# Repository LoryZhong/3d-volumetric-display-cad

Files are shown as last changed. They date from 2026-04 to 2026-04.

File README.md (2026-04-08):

# 3D Volumetric Display — Hardware Design Files

Mechanical CAD and PCB design files for a rotational swept-volume volumetric display based on persistence of vision (POV). Structural components were designed in SolidWorks and fabricated by FDM 3D printing (PLA, with PETG for the motor damper). The custom HUB75E adapter PCB was designed in KiCad.

This repository accompanies the software driver at [LoryVox](https://github.com/LoryZhong/LoryVox).

## Assembly Overview

The mechanical structure is divided into three subsystems:

### Rotate Part — Core Rotating Assembly

The central rotating body that carries all on-rotor electronics. Includes the core (with Raspberry Pi 4 mounting bosses and bearing locators), plug, slip-ring cylinder (sized for the ASL9013 2-line slip ring), bottom bearing ring, GT2 pulley bore, half-disc photo-interrupter flag, and top cover.

- Upper bearing: 6015 deep-groove ball bearing (bore large enough for the Raspberry Pi to pass through during assembly)
- Lower bearing: 6804 deep-groove ball bearing (bore sized for the ASL9013 slip ring)
- Bearings are retained by interference-fit bosses — no adhesive required

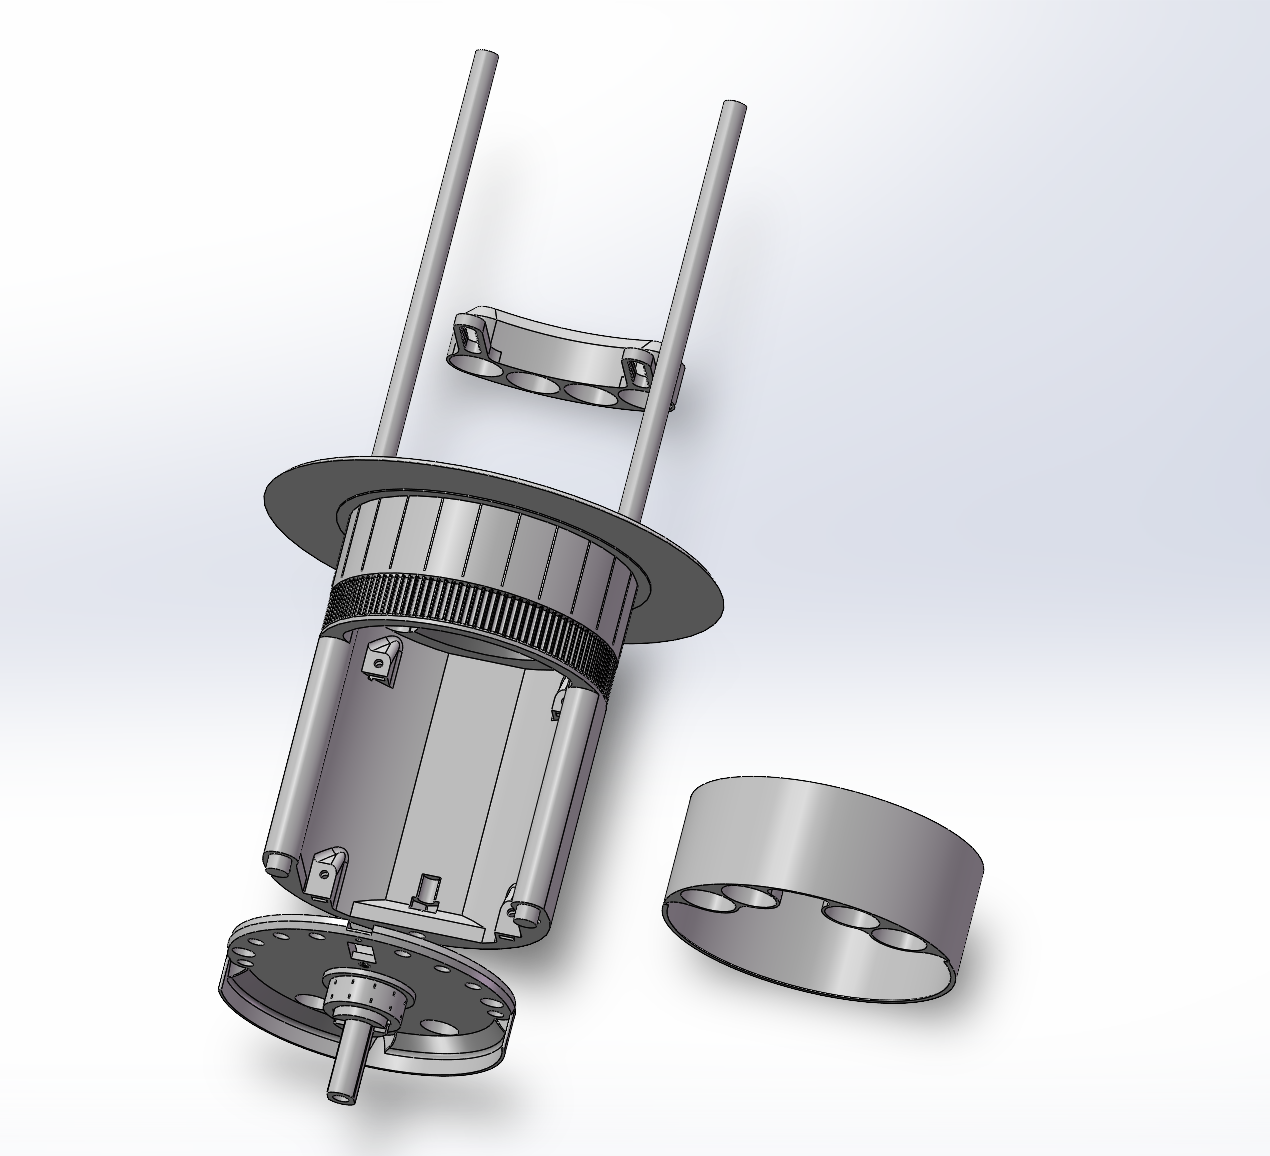
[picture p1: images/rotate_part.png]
Rotate Part


**Contents of `rotate-part/`:** Core, plug, slip-ring cylinder, bottom bearing ring, half-disc flag, top cover.

### Frame — LED Panel Mounting Frame

Rectangular frames that hold each HUB75E LED panel (P2.5 64x64) at the correct radial distance from the rotation axis. Carbon-fibre rods (6 mm dia.) connect the frames to the core assembly. Version 2 redesigned the rod socket diameter to 6.1 mm with clearance chamfers, allowing post-print finishing with a 6.1 mm drill bit.

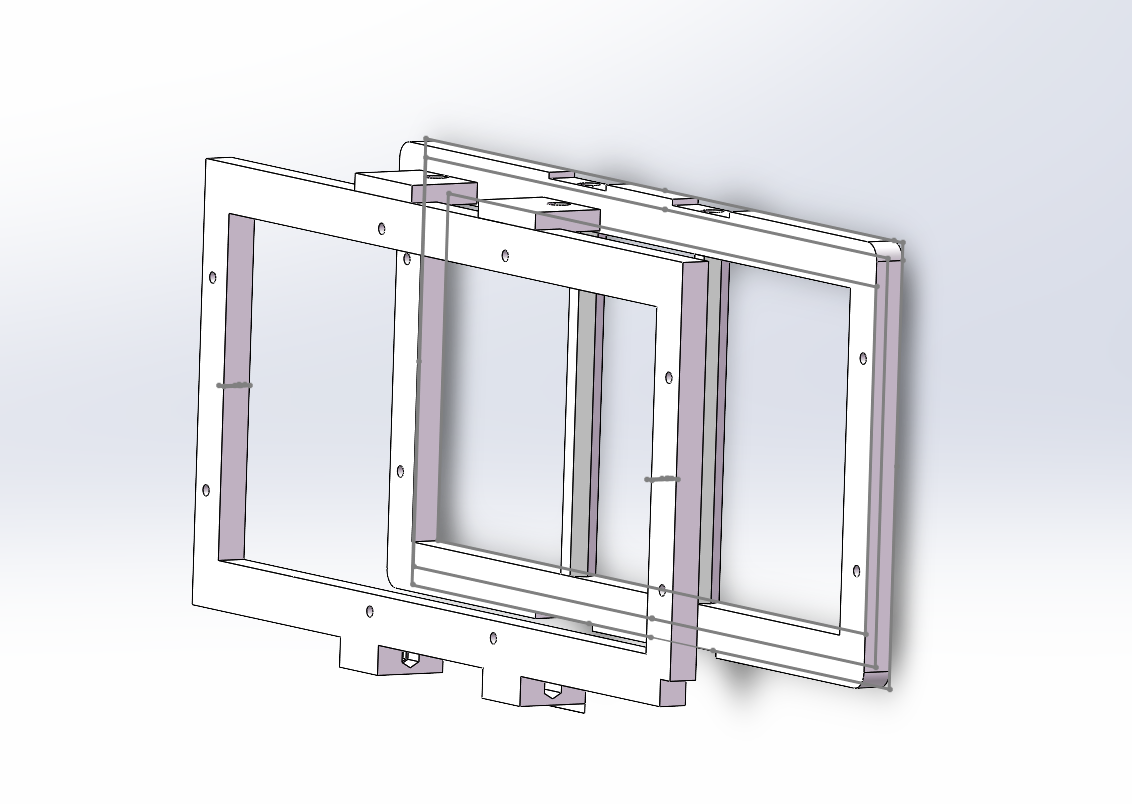
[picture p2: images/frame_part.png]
Frame


**Contents of `frame/`:** LED panel frame (Version 2), rod socket geometry.

### Support Part — Stationary Base and Motor Mount

The non-rotating platform that houses the power supply, motor, brush holder (AS-PL ABH6004S), and photo-interrupter sensor. Includes the sliding motor-mount bracket for GT2 belt tension adjustment and the PETG motor damper for vibration attenuation.

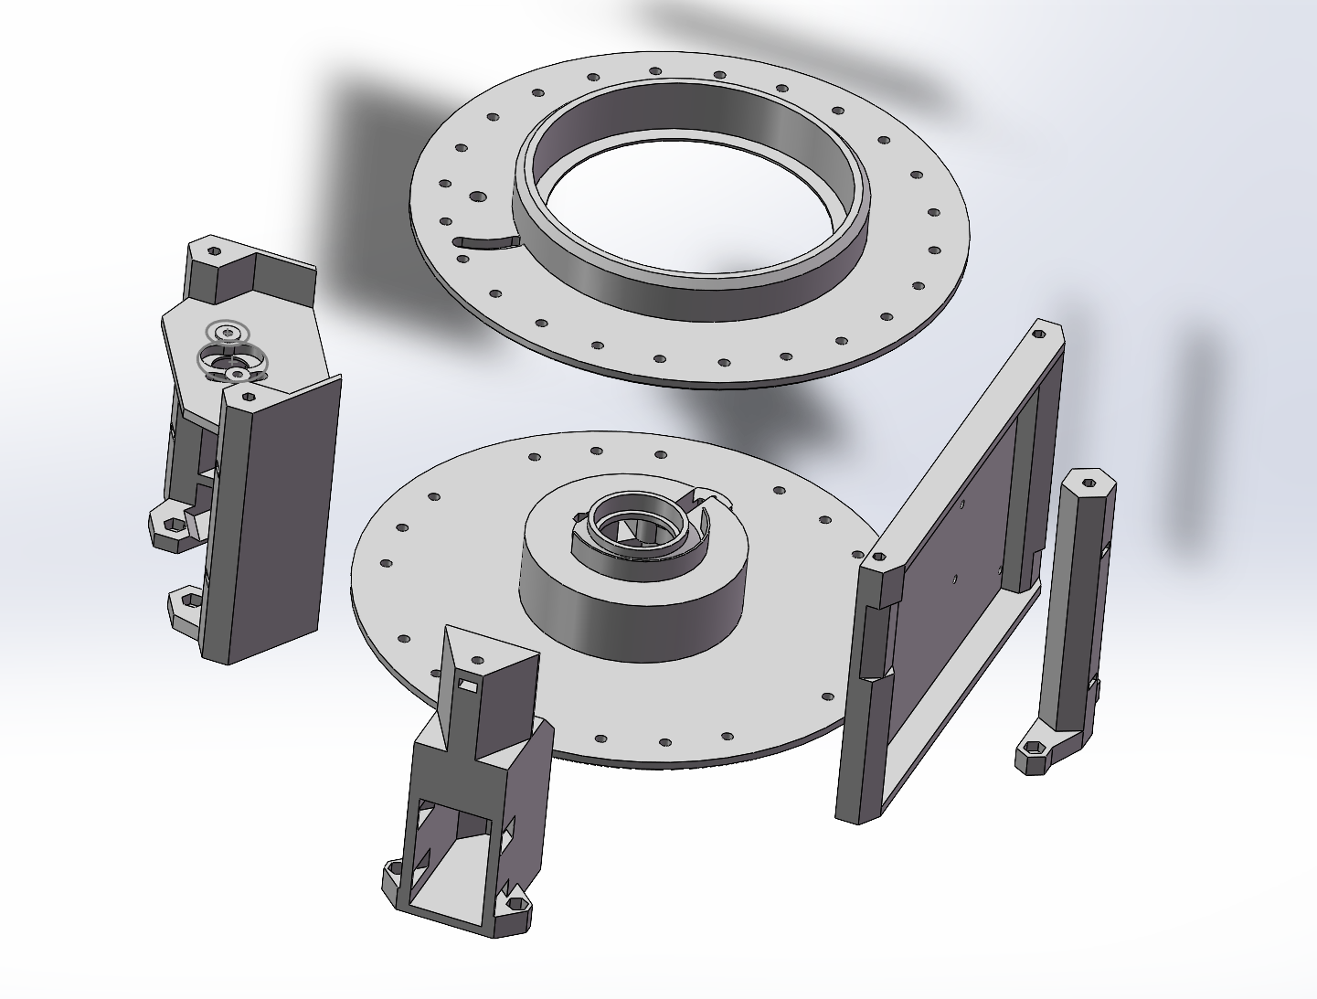
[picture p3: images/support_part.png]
Support Part


**Contents of `support-part/`:** Stationary base, motor mount (sliding slot), motor damper (PETG), partial enclosure panels.

### PCB — Custom HUB75E Adapter Board

KiCad project for the 3.3 V-to-5 V level-shifting adapter between the Raspberry Pi 4 GPIO header and two HUB75E LED panel connectors. Uses three 74HCT245 octal bus transceivers (SOIC-20) with per-IC 100 nF decoupling capacitors. Includes a JST-XH 3-pin socket for the photo-interrupter and a JST-XH 2-pin socket for DC-DC power input.

**Contents of `pcb/`:** KiCad project (`.kicad_pro`, `.kicad_sch`, `.kicad_pcb`), BOM (`.csv`), schematic PDF, fabrication Gerbers (`.zip`).

| PCB Parameter | Value |
|---|---|
| Layers | 2 |
| Substrate | FR-4, 0.8 mm |
| Copper | 1 oz |
| Min trace | 0.33 mm |
| Via drill/ring | 0.4/1.1 mm |
| Finish | HASL lead-free |

## Printing Notes

| Parameter | Value |
|---|---|
| Material | PLA (structural parts), PETG (motor damper) |
| Layer height | 0.2 mm |
| Infill | 20–40% (structural), 100% (bearing bosses) |
| Fasteners | M4 hex-socket screws throughout |

## License

MIT

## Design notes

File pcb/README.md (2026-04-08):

# Custom HUB75E Adapter PCB

Custom adapter PCB for the 3D volumetric display project, **based on and modified from** the [Active-3 adapter](https://github.com/hzeller/rpi-rgb-led-matrix/tree/master/adapter/active-3) by Henner Zeller (part of the [rpi-rgb-led-matrix](https://github.com/hzeller/rpi-rgb-led-matrix) project).

## What was changed

The original Active-3 design supports up to 3 panel chains with 4x 74HCT245 ICs. This version was modified for the volumetric display rotor:

- Reduced from 3 HUB75 outputs to 2 (matching the dual-panel rotating arm)
- Reduced from 4x to 3x 74HCT245 ICs
- Reworked board outline to fit inside the 3D-printed rotor core
- Added JST-XH 3-pin socket for photo-interrupter connection
- Added JST-XH 2-pin socket for DC-DC 5V power input
- Adjusted trace routing for improved CLK signal integrity (straighter path, increased clearance)
- Corrected via dimensions: drill 0.4 mm / annular ring 1.1 mm
- Minimum trace width: 0.33 mm (widened from original)
- Board thickness: 0.8 mm (thinner than standard 1.6 mm, to reduce rotor weight)

## Files in this directory

| File | Status | Description |
|---|---|---|
| `active3-rpi-hub75-adapter.kicad_pcb` | **Modified** | PCB layout with custom modifications |
| `active3-rpi-hub75-adapter.kicad_sch` | **Modified** | Schematic with custom modifications |
| `active3-rpi-hub75-adapter.kicad_pro` | From original | KiCad project file (may not reflect all changes) |
| `active3-rpi-hub75-adapter.kicad_prl` | From original | KiCad local settings |
| `active3-rpi-hub75-adapter.csv` | From original | BOM (does not reflect modified design) |
| `active3-rpi-hub75-adapter-fab.zip` | From original | Gerbers (does not reflect modified design) |
| `schematic.pdf` | From original | Schematic PDF (does not reflect modified design) |

> **Note:** Only the `.kicad_pcb` and `.kicad_sch` files reflect the actual custom design used in the project. The other files are inherited from the original Active-3 project and may not match the modified board. Refer to the schematic and PCB layout files for the as-built design.

## Original design credit

Based on the Active-3 adapter by [Henner Zeller](https://github.com/hzeller), licensed under the rpi-rgb-led-matrix project. The original design is an open-source KiCad PCB using HCT245 level shifters to interface Raspberry Pi 3.3V GPIO with 5V HUB75 panels.

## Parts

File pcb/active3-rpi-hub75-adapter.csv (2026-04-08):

编号 | 位号 | 封装 | 数量 | 名称 | 供应商编号
1 | C1,C2,C3 | C_0805_2012Metric | 3 | 100n
2 | P1 | Pin_Header_Straight_2x20 | 1 | CONN_02X20
3 | Panel-1,Panel-2 | IDC-Header_2x08_P2.54mm_Vertical | 2 | CONN_02X08
4 | P20,P21 | 1pin | 2 | CONN_01X01
5 | R1 | R_0805_2012Metric | 1 | 10k
6 | P5,P4 | Pin_Header_Straight_1x01 | 2 | GND
7 | C5 | CP_Radial_D6.3mm_P2.50mm | 1 | 22u
8 | P3 | Pin_Header_Straight_1x01 | 1 | RxD
9 | C6 | C_1206_3216Metric | 1 | 22u
10 | P2 | Pin_Header_Straight_1x01 | 1 | +5V
11 | P6,P8 | Pin_Header_Straight_1x02 | 2 | CONN_01X02
12 | P7 | Pin_Header_Straight_1x02 | 1 | CONN_02X01
13 | U1,U2,U3 | SOIC-20W_7.5x12.8mm_P1.27mm | 3 | 74HCT245
14 | REF** | Symbol_OSHW-Logo_SilkScreen | 1 | Symbol_OSHW-Logo_SilkScreen
15 | R_PHOTO1 | R_0805_2012Metric | 1 | 1K
16 | J_PHOTO1 | JST_XH_B3B-XH-A_1x03_P2.50mm_Vertical | 1 | Conn_01x03
17 | C_PHOTO1 | C_0805_2012Metric | 1 | 100nF

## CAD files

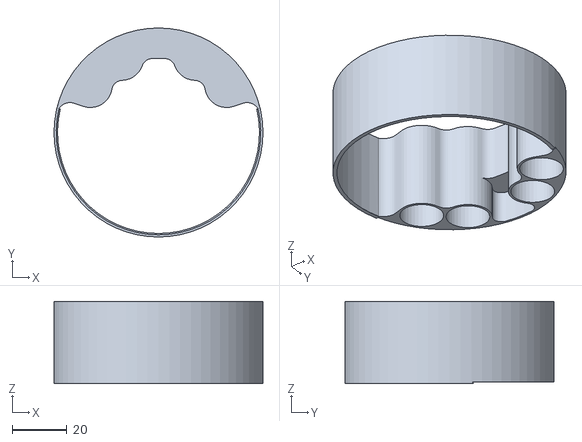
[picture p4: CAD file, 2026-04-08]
rotate-part/loweight.STL
76.6 x 76.6 x 30.1

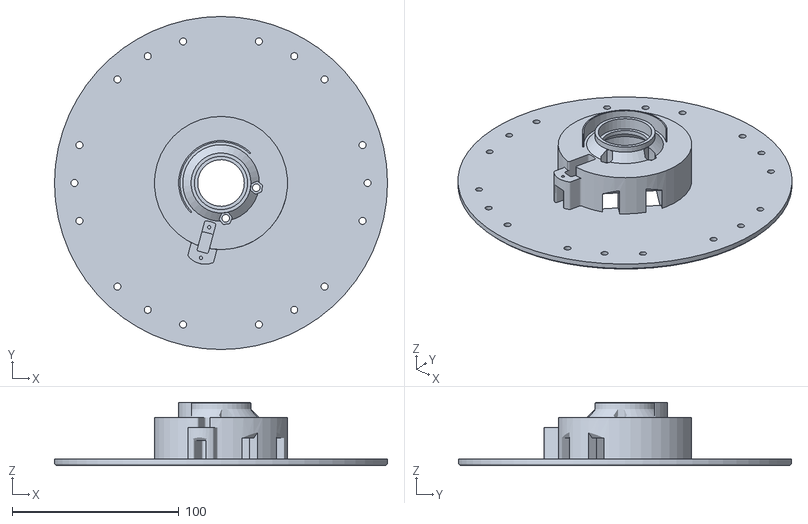
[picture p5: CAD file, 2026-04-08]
support-part/floor1.STL
200.0 x 200.0 x 38.0

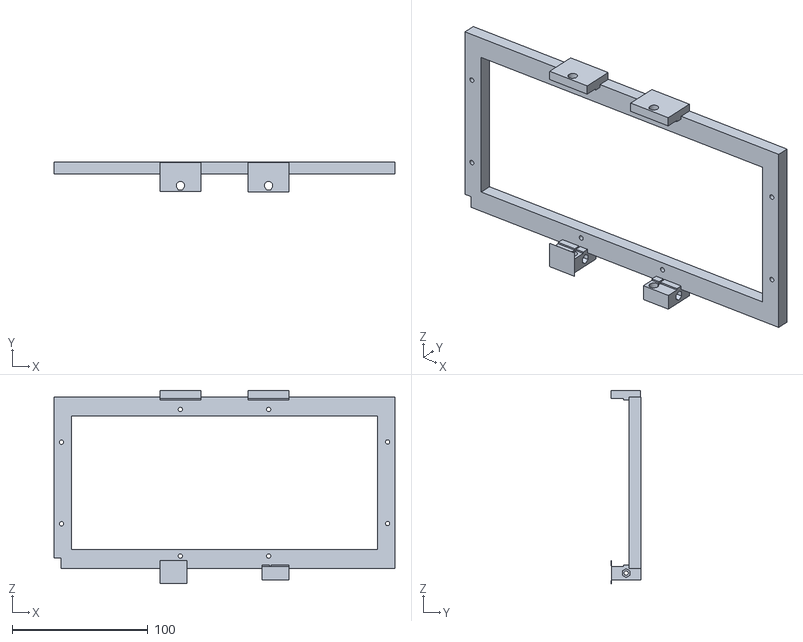
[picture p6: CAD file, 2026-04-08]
frame/Frame2—3.25.STL
251.0 x 21.8 x 142.2

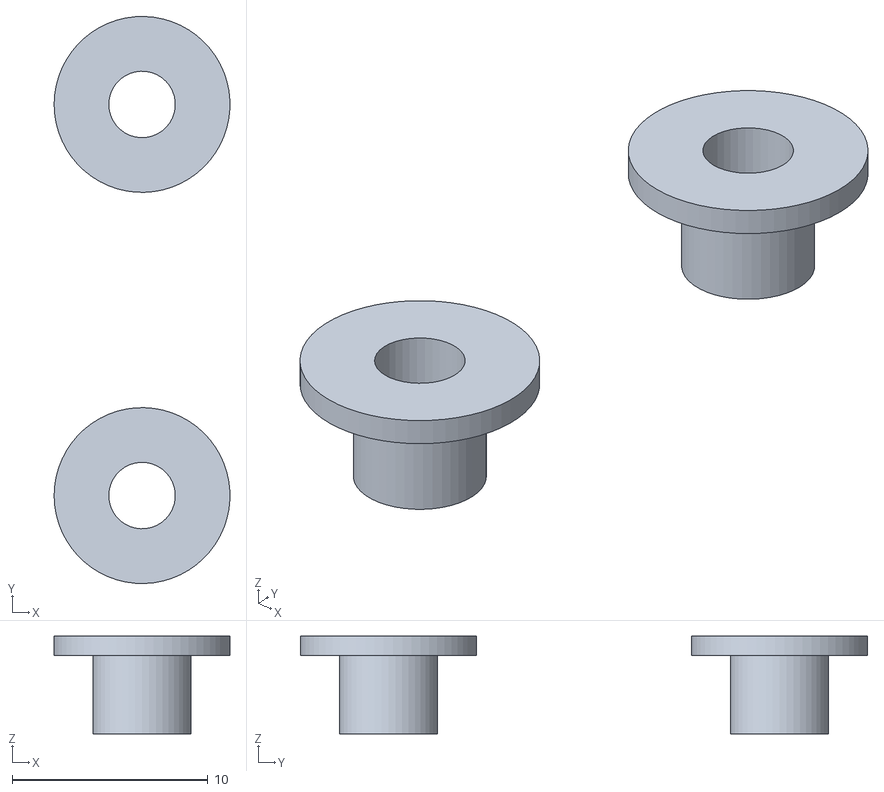
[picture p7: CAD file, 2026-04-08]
support-part/skewdamper.STL
8.99 x 29.0 x 5.00

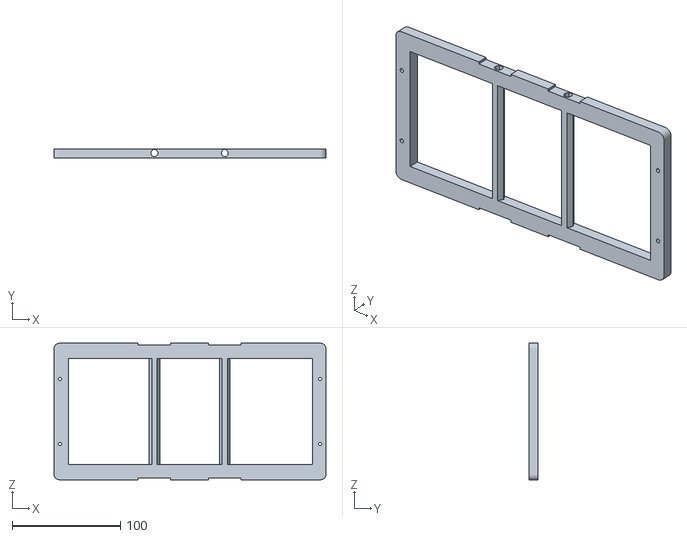
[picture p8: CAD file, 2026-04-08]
frame/Frame1_3.25.STL
251.0 x 8.50 x 126.0

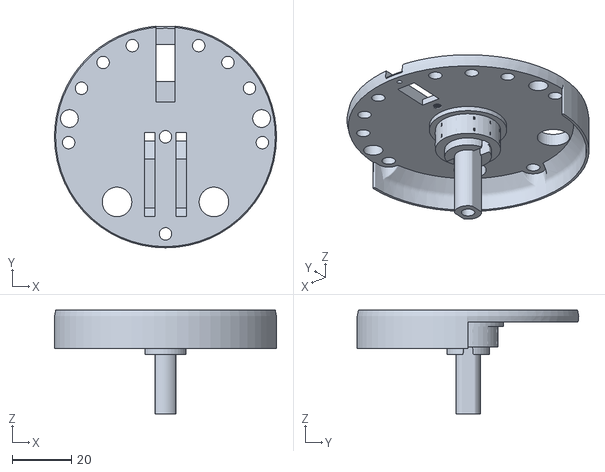
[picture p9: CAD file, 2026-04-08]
rotate-part/newplug.STL
75.0 x 74.9 x 35.0

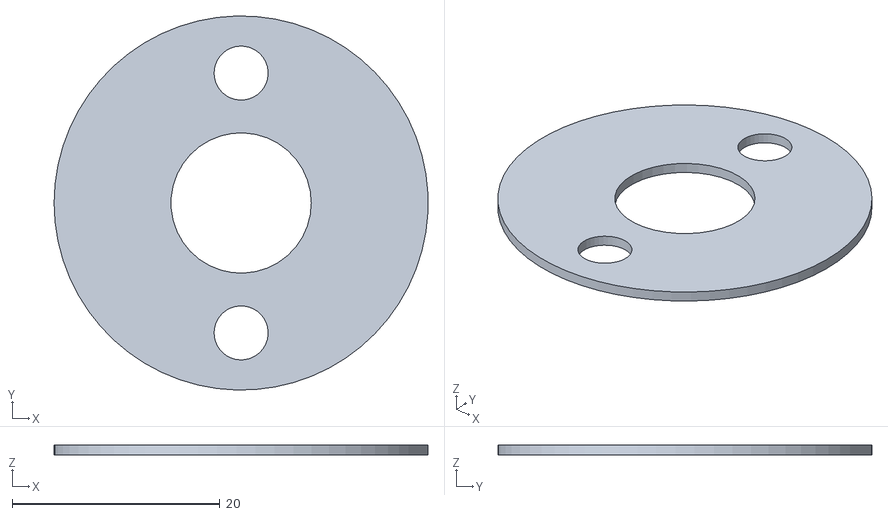
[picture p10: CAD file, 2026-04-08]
support-part/motordamper.STL
36.0 x 36.0 x 1.00

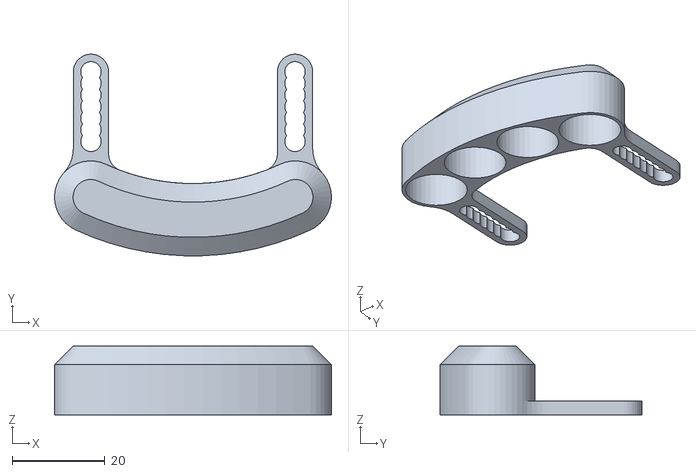
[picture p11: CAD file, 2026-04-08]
rotate-part/weights.STL
59.7 x 43.4 x 14.8

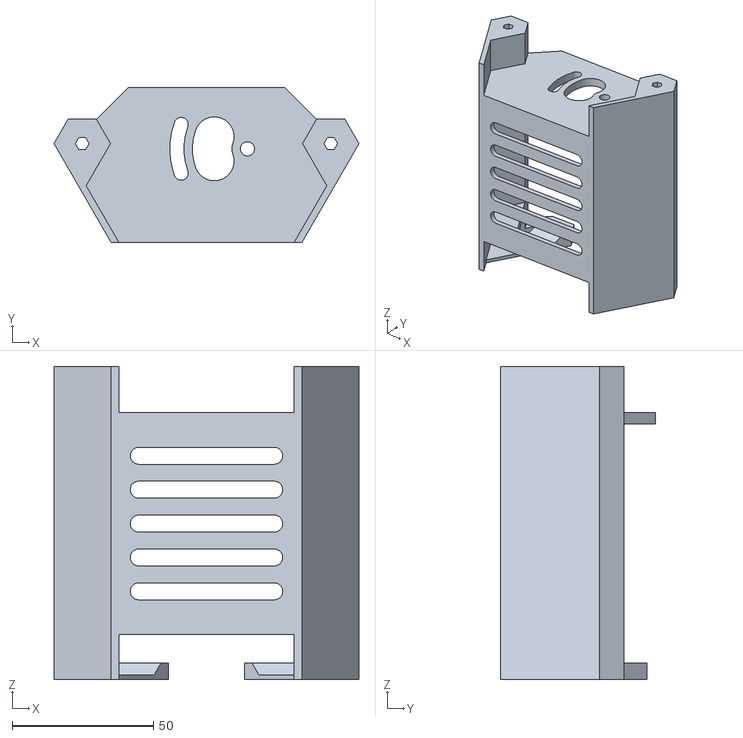
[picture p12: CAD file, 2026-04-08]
support-part/motorleg (1).STL
108.0 x 54.8 x 111.0

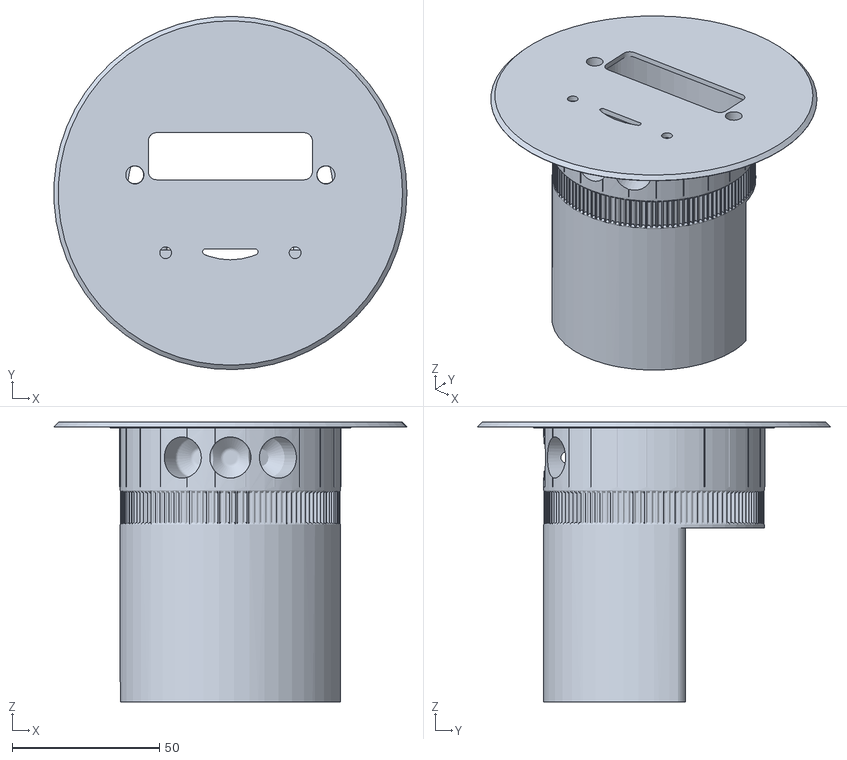
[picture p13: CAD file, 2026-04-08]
rotate-part/core3.25.STL
119.9 x 120.0 x 95.0

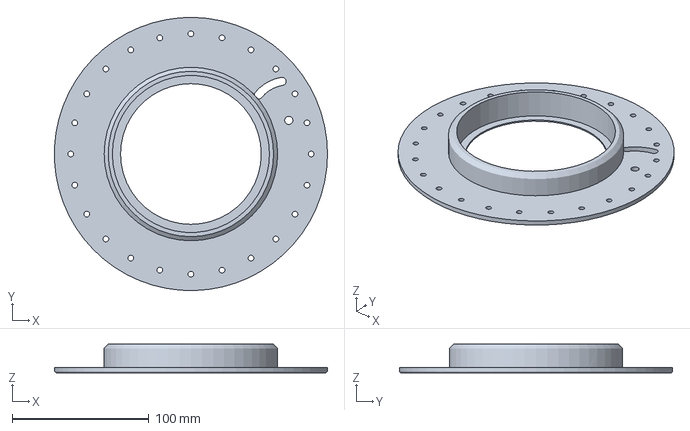
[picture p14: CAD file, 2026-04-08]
support-part/top.3mf
199.9 x 199.9 x 21.0 mm

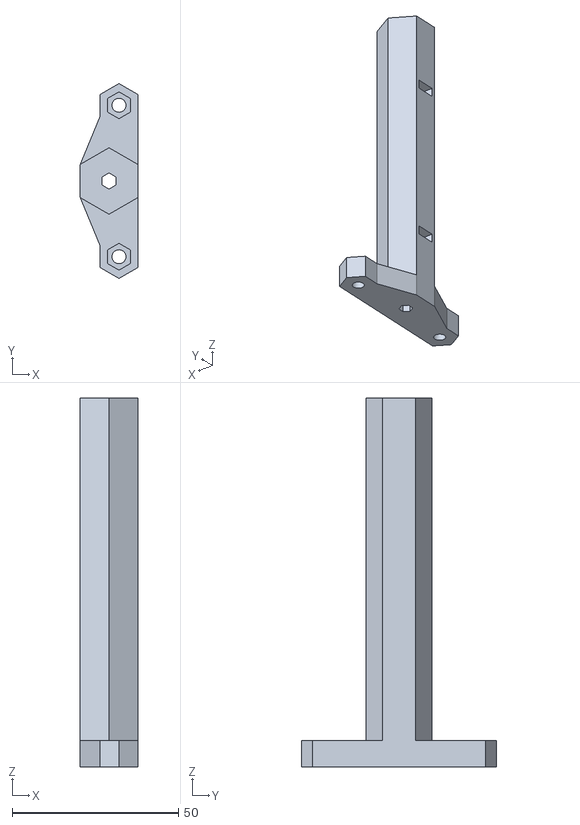
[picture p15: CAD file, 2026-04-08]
support-part/peg.STL
17.3 x 58.6 x 111.0

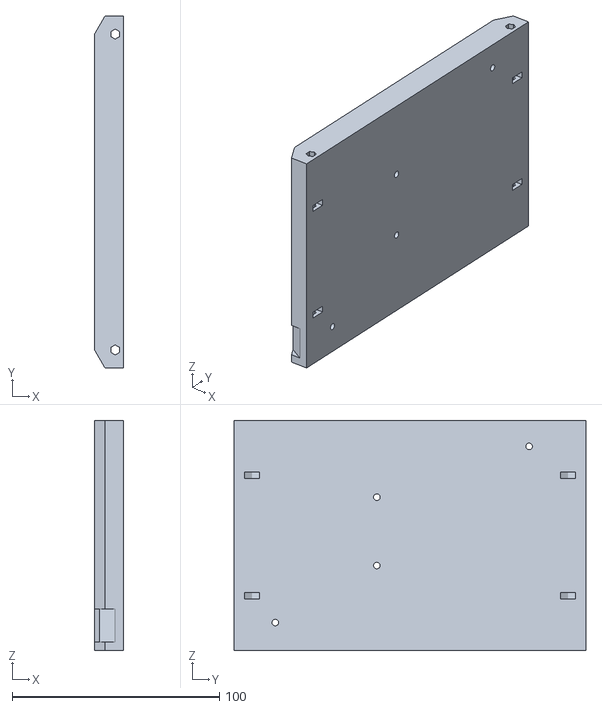
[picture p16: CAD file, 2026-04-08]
support-part/powerpak.STL
14.0 x 169.7 x 111.0

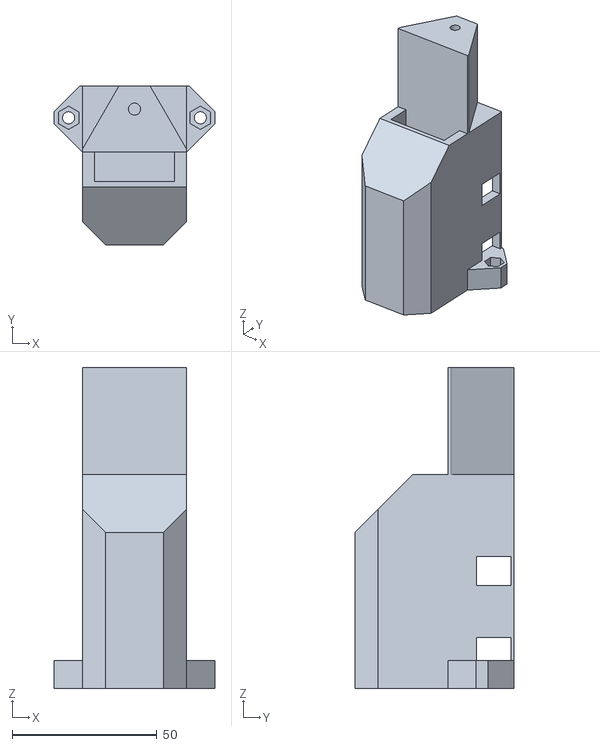
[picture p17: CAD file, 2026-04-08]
support-part/socot.STL
55.6 x 55.0 x 111.0

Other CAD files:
frame/framepart.SLDASM
rotate-part/rotatepart.SLDASM
support-part/supportpart.SLDASM

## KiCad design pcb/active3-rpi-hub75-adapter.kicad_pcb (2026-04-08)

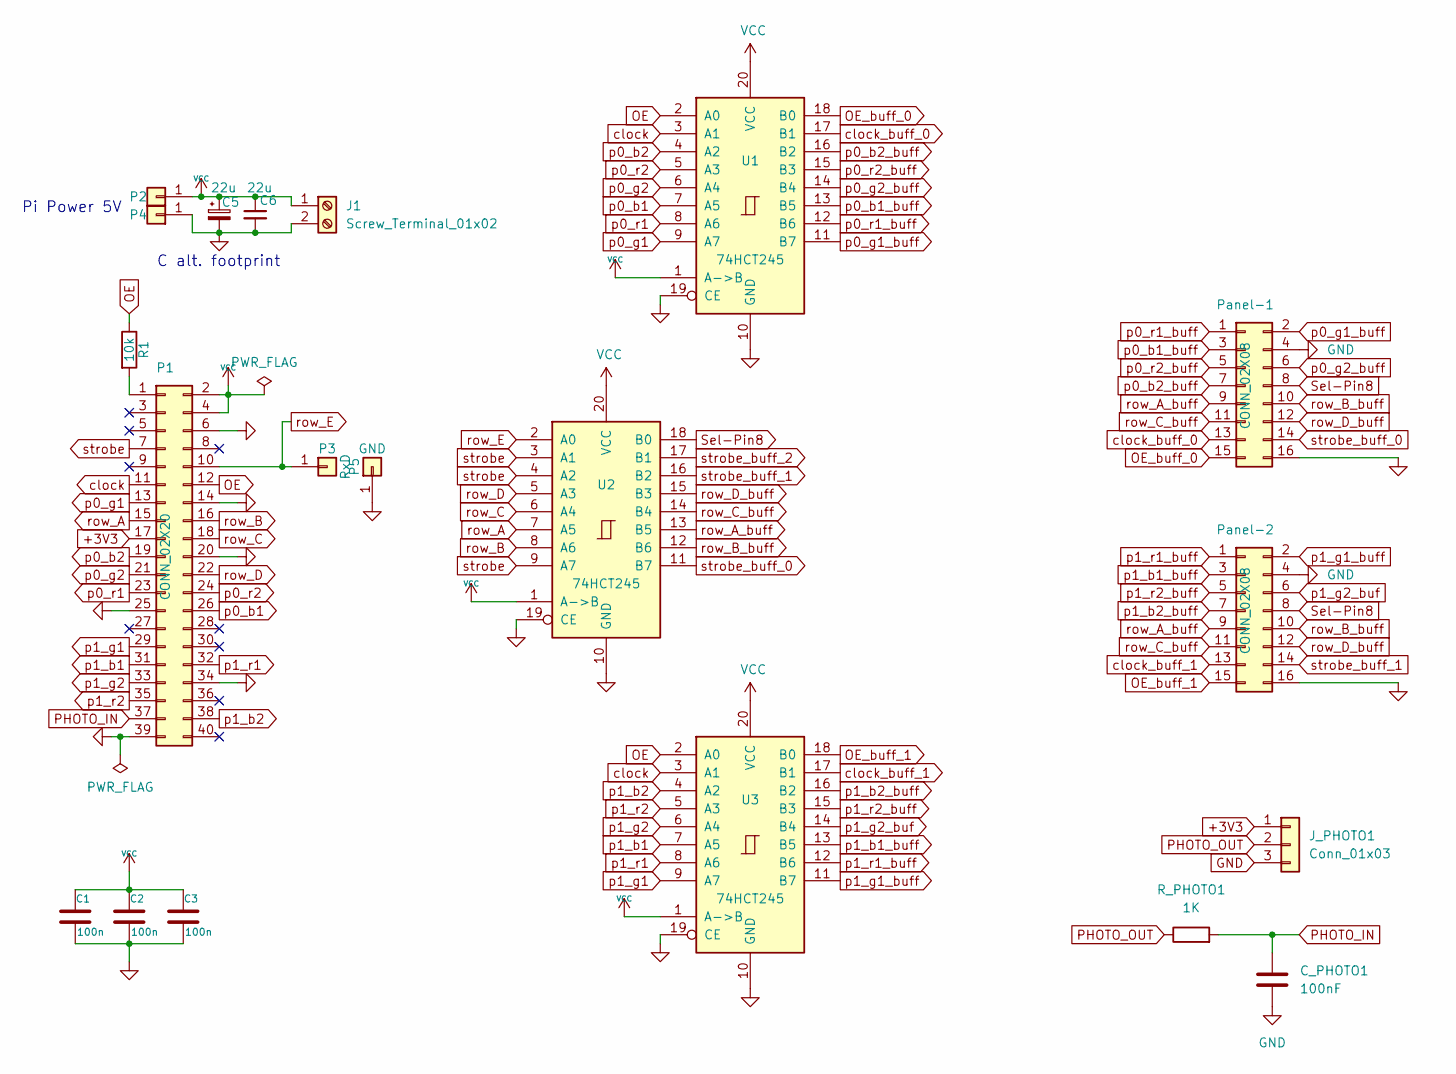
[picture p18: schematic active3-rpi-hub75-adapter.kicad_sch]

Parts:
C1, C2, C3: 100n; C_0805_2012Metric
C5: 22u; CP_Radial_D6.3mm_P2.50mm
C6: 22u; C_1206_3216Metric
C_PHOTO1: 100nF; C_0805_2012Metric
J1: Screw_Terminal_01x02
J_PHOTO1: Conn_01x03; JST_XH_B3B-XH-A_1x03_P2.50mm_Vertical
P1: CONN_02X20; Pin_Header_Straight_2x20
P2: +5V; Pin_Header_Straight_1x01
P3: RxD; Pin_Header_Straight_1x01
P4, P5: GND; Pin_Header_Straight_1x01
Panel-1, Panel-2: CONN_02X08; IDC-Header_2x08_P2.54mm_Vertical
R1: 10k; R_0805_2012Metric
R_PHOTO1: 1K; R_0805_2012Metric
U1, U2, U3: 74HCT245; SOIC-20W_7.5x12.8mm_P1.27mm

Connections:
+3V3: J_PHOTO1.1, P1.17
GND: C1.2, C2.2, C3.2, C5.2, C6.2, C_PHOTO1.2, J1.2, J_PHOTO1.3, P1.6, P1.14, P1.20, P1.25, P1.34, P1.39, P4.1, P5.1, Panel-1.4, Panel-1.16, Panel-2.4, Panel-2.16, U1.10 (GND), U1.19 (CE), U2.10 (GND), U2.19 (CE), U3.10 (GND), U3.19 (CE)
unnamed: P1.1, R1.2
OE: P1.12, R1.1, U1.2 (A0), U3.2 (A0)
OE_buff_0: Panel-1.15, U1.18 (B0)
OE_buff_1: Panel-2.15, U3.18 (B0)
PHOTO_IN: C_PHOTO1.1, P1.37, R_PHOTO1.2
PHOTO_OUT: J_PHOTO1.2, R_PHOTO1.1
Sel-Pin8: Panel-1.8, Panel-2.8, U2.18 (B0)
VCC: C1.1, C2.1, C3.1, C5.1, C6.1, J1.1, P1.2, P1.4, P2.1, U1.1 (A->B), U1.20 (VCC), U2.1 (A->B), U2.20 (VCC), U3.1 (A->B), U3.20 (VCC)
clock: P1.11, U1.3 (A1), U3.3 (A1)
clock_buff_0: Panel-1.13, U1.17 (B1)
clock_buff_1: Panel-2.13, U3.17 (B1)
p0_b1: P1.26, U1.7 (A5)
p0_b1_buff: Panel-1.3, U1.13 (B5)
p0_b2: P1.19, U1.4 (A2)
p0_b2_buff: Panel-1.7, U1.16 (B2)
p0_g1: P1.13, U1.9 (A7)
p0_g1_buff: Panel-1.2, U1.11 (B7)
p0_g2: P1.21, U1.6 (A4)
p0_g2_buff: Panel-1.6, U1.14 (B4)
p0_r1: P1.23, U1.8 (A6)
p0_r1_buff: Panel-1.1, U1.12 (B6)
p0_r2: P1.24, U1.5 (A3)
p0_r2_buff: Panel-1.5, U1.15 (B3)
p1_b1: P1.31, U3.7 (A5)
p1_b1_buff: Panel-2.3, U3.13 (B5)
p1_b2: P1.38, U3.4 (A2)
p1_b2_buff: Panel-2.7, U3.16 (B2)
p1_g1: P1.29, U3.9 (A7)
p1_g1_buff: Panel-2.2, U3.11 (B7)
p1_g2: P1.33, U3.6 (A4)
p1_g2_buf: Panel-2.6, U3.14 (B4)
p1_r1: P1.32, U3.8 (A6)
p1_r1_buff: Panel-2.1, U3.12 (B6)
p1_r2: P1.35, U3.5 (A3)
p1_r2_buff: Panel-2.5, U3.15 (B3)
row_A: P1.15, U2.7 (A5)
row_A_buff: Panel-1.9, Panel-2.9, U2.13 (B5)
row_B: P1.16, U2.8 (A6)
row_B_buff: Panel-1.10, Panel-2.10, U2.12 (B6)
row_C: P1.18, U2.6 (A4)
row_C_buff: Panel-1.11, Panel-2.11, U2.14 (B4)
row_D: P1.22, U2.5 (A3)
row_D_buff: Panel-1.12, Panel-2.12, U2.15 (B3)
row_E: P1.10, P3.1, U2.2 (A0)
strobe: P1.7, U2.3 (A1), U2.4 (A2), U2.9 (A7)
strobe_buff_0: Panel-1.14, U2.11 (B7)
strobe_buff_1: Panel-2.14, U2.16 (B2)
strobe_buff_2: U2.17 (B1)

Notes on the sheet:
Pi Power 5V
C alt. footprint

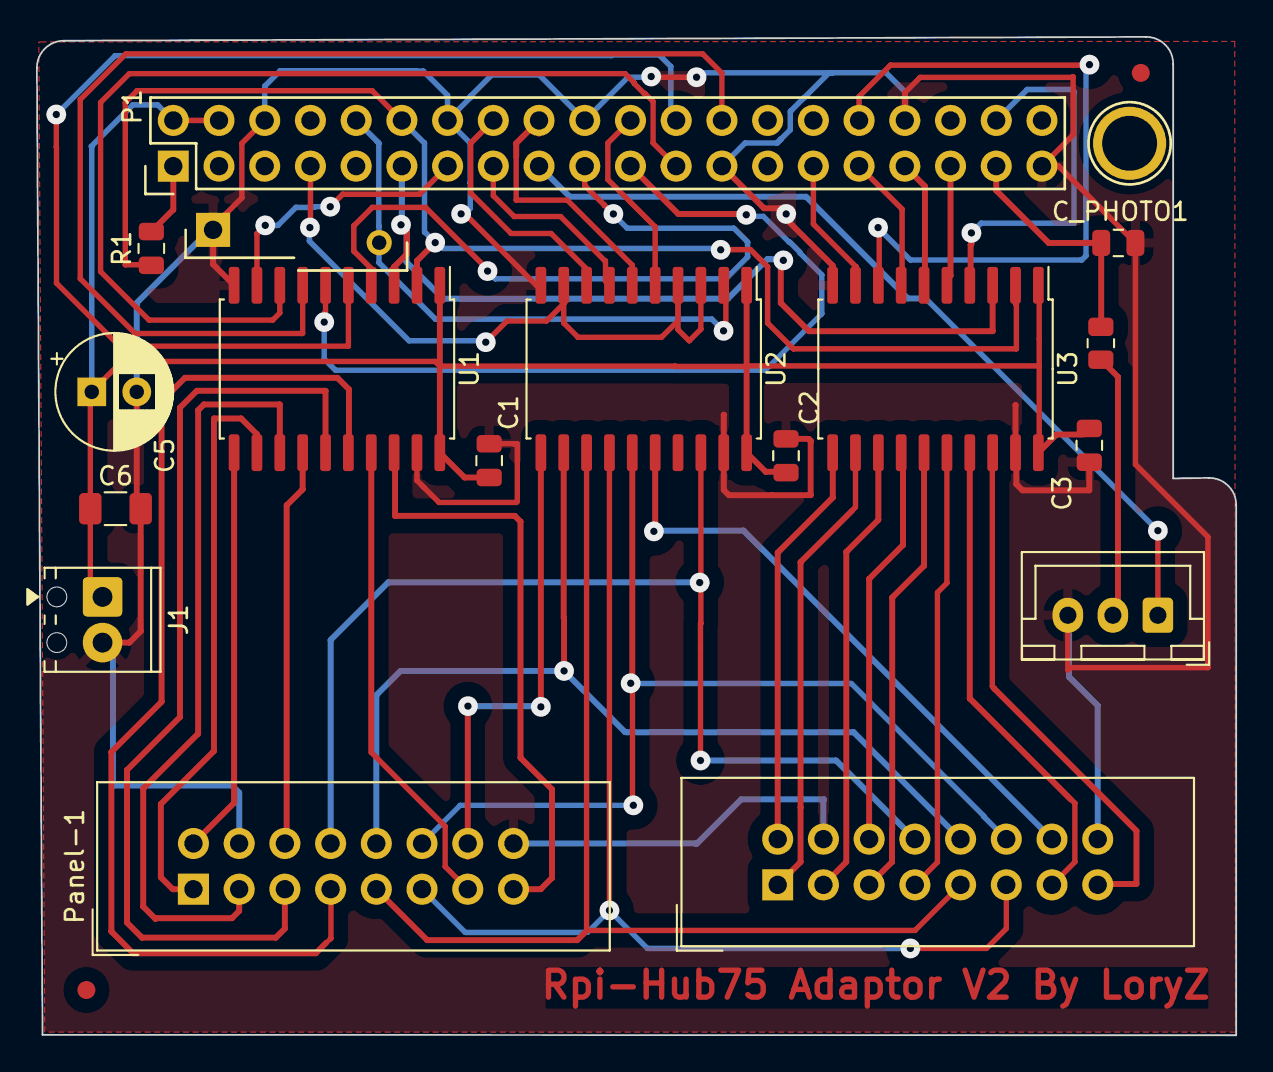
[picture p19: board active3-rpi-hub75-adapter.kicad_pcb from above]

Board: 2 copper layers, 66.6 x 55.5 mm, 19 parts (0 on the bottom side), 49 nets.

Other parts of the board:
P21: CONN_01X01; 1pin

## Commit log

2026-04-08 Initial commit: repo structure with README and CAD preview images
    Three subsystem directories (rotate-part, frame, support-part) for
    SolidWorks/STL files to be added. README includes assembly overview
    with rendered CAD images.
2026-04-08 Add STL and SolidWorks assembly files for all subsystems
    - rotate-part: core, plug, weights, low-weight (4 STL + 1 SLDASM)
    - frame: two panel frame versions (2 STL + 1 SLDASM)
    - support-part: base, motor mount, damper, top cover, etc. (8 STL/3MF + 1 SLDASM)
    [Frame1_3.25.STL, Frame2—3.25.STL, core3.25.STL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]
2026-04-08 Add KiCad PCB design files and update README
    HUB75E adapter board: KiCad project, schematic, PCB layout,
    BOM, fabrication Gerbers, and schematic PDF.
    [active3-rpi-hub75-adapter.csv, active3-rpi-hub75-adapter.kicad_pcb, active3-rpi-hub75-adapter.kicad_sch]
2026-04-08 Rewrite PCB README to document modifications from Active-3 original
    Clarifies which files are custom (.kicad_pcb, .kicad_sch) vs
    inherited from the original Active-3 design.
